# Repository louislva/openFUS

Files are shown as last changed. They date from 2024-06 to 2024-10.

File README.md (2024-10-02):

# openFUS: a cheap, open-source, easy to replicate FUS device for hackers & researchers

View [current design (subject to change)](/design/) 

### Background

Transcranial focused ultrasound (tFUS) is a non-invasive neuromodulation technique, which has millimeter precision and can reach any depth in the brain. It's safe, and has been used in humans to:

- [improve mood](https://www.frontiersin.org/articles/10.3389/fnhum.2020.00052)
- [reduce sensitivity to pain](https://www.jneurosci.org/content/44/8/e1011232023) (and [again](https://www.sciencedirect.com/science/article/pii/S1935861X20302746))
- [decrease amygdala activity (for treating anxiety)](<https://www.brainstimjrnl.com/article/S1935-861X(24)00040-8/fulltext>)

It's incredible that we have a **non-invasive** way to do the equivalent of putting a wire _anywhere_ in the brain and stimulating it. Why isn't this everywhere?

1. tFUS is relatively new & underdeveloped. It's quickly gaining steam (see [Prophetic](https://x.com/PropheticAI), etc.), but good human studies really only started coming out in the late 2010s!
2. It's still niche in academia, and the hardware is expensive. This means relatively few labs can do it.
3. No good treatment protocols, which makes effect sizes sub-therapeutic. We have the tool but we don't quite know how to use it (sonication parameters, environment, sequence / repetitions, etc.)

### How tFUS works

You wouldn't expect ultrasound could modulate the brain — electric currents or magnetic fields, sure, but acoustic waves? Apparently yes! The mechanisms are still unknown, but by changing the parameters of the ultrasound pulses, you can control whether you get a net excitatory or inhibitory effect.

Then, in order to get the ultrasound to the right part of the brain, you need to focus it. This can be done in many ways, but the easiest to illustrate, is if you have a bunch of weak ultrasound beams, which all converge at the same point:

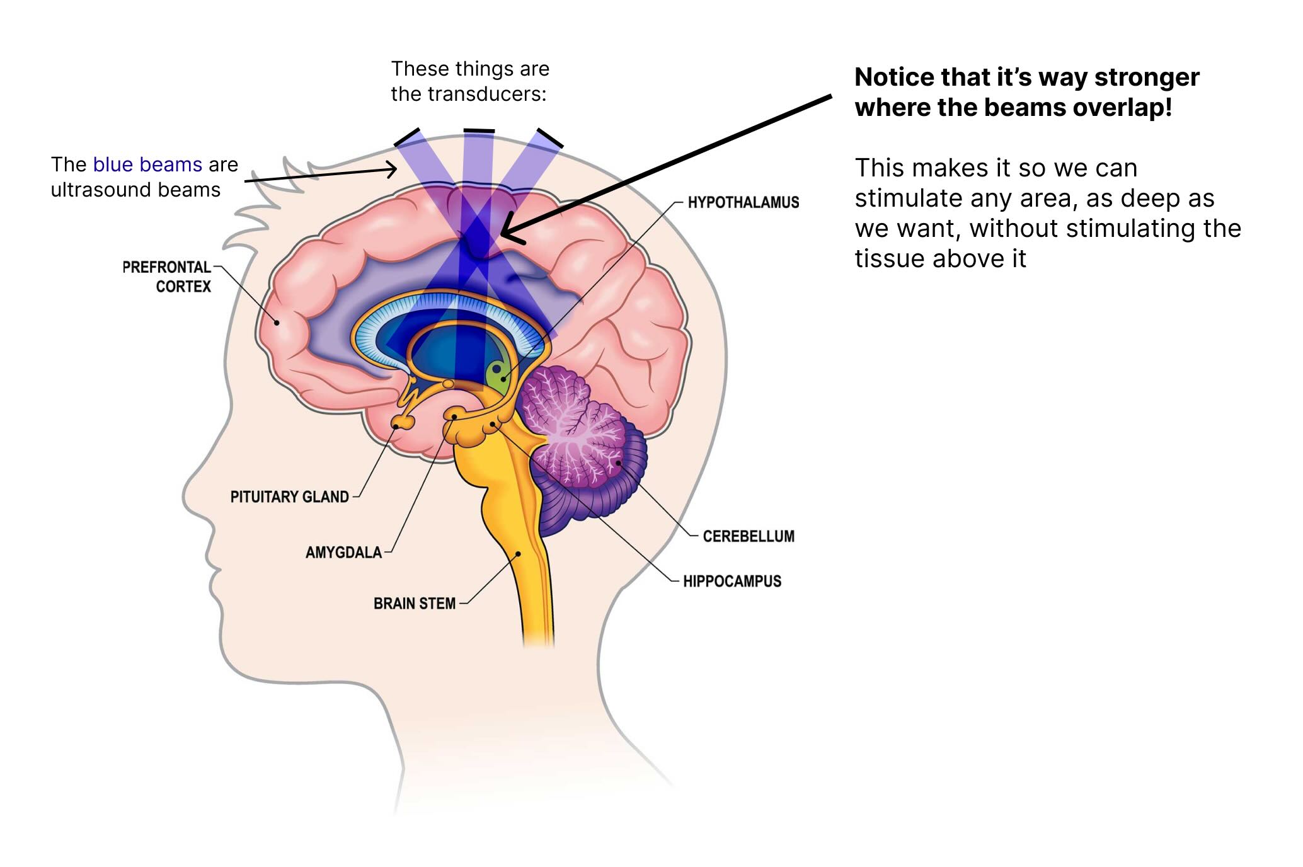
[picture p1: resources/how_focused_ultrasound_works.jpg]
how focused ultrasound works


The beam will be too weak to do anything at the surface, but at the focal point, it will be strong enough to affect neurons.

### Motivation for **openFUS**

Let's compare tFUS to EEG. Nowadays, every neuroscience _undergrad_ is working with EEG (because [OpenBCI](https://openbci.com/) sells $1000 EEGs). Even hackers and psychonauts can use it to make discoveries (for example, [Jhourney](https://x.com/stephen_zerfas/status/1755149844921057744) finding neural correlates of the 2nd jhana).

We've not reached this moment with tFUS yet, but when we do, it's gonna lead to [an explosion in neuroscience](https://sarahconstantin.substack.com/p/testing-human-augmentation) since we can easily and rapidly test hypotheses. Sonicate one area, give a subjective report, take an fMRI, repeat.

For this neuroscience renaissance to happen, **FUS needs to be more accessible**. We need an open-source starting point for engineers to build on top of, and independent researchers to buy and use.

**North star:** make a device theoretically capable of replicating ["Transcranial Focused Ultrasound to the Right Prefrontal Cortex Improves Mood and Alters Functional Connectivity in Humans"](https://www.frontiersin.org/articles/10.3389/fnhum.2020.00052), for less than $1k.

### Contributing

We need your help! Here are some things you can help out with:

- Great software (for neuronavigation, setting sonication params, self-blinding, peer-to-peer science, etc.)
- Great product design (for the handheld device itself)
- Driving electronics (e.g. amplify to generate LOTS of power as cheap as possible)
- Funding (we're not spending any time fundraising, but if you can wire cash with low overhead, it'd help a lot)

If you're interested in contributing, please reach out to Louis Arge [on Twitter](https://x.com/louisvarge), [by email](mailto:louis@muditalabs.ai), or if you have something very concrete: just open a PR.

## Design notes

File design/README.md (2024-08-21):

# openFUS design (subject to change)

This document serves as the reference for the current design of the openFUS device. It is not final, and subject to change as we iterate & learn.

## Stack

Here are the components, roughly listed from back to front:

- **"Driver" box**
    - **RF-proof case** (is this necessary?)
    - **Arduino** or Raspberry Pi
    - **[Driver electronics](/design/driving-and-wattage.md)**
        - AD9833
        - Coupling capacitor
        - Amplifier
- **"Pointer" handheld**
    - **Housing (water-proof)**
    - **Angled back panel**, to reflect any waves that end up making it through backing away orthogonally
    - **[Backing](/design/backing.md):** absorb waves that come out through the back, so they don't reflect and interfere in the forward direction
    - **Wires** that connect silver electrodes & the Driver
    - **[PZT-5H disc](/design/piezoelectric-element.md):** raw transducer element
    - **[Impedance matching (PZT to lens)](/design/impedance-matching.md):** Quarter-wave transformer
    - **[Lens](/design/lens.md):** concave lens, to focus the ultrasound waves
        - Material: Probably TPX/Polymethylpentene, which has almost same impedence as water/ultrasound gel/tissue
        - Shape: concave, since accoustic lenses are opposite of optical lenses (concave to focus, convex to diverge)
        - Exact shape: Use [`make_lens.py`](/make_lens.py) to design a lens - unsure this is actually right, let's see
        - Manufacturing: Probably buy a rod of TPX, slice it, and machine it
- **Ultrasound gel:** to fill the lens & make contact with skull or water tank, and couple the ultrasound waves to the skull
- Note: The electrodes to power the PZT-5H can be run through the impedance matching, if it's conductive (e.g. silver epoxy might be)

## Bill of materials (priced for 10 units)

- Arduino: $25
- AD9833: $12
- THS3091: $12
- Power Supply: $100
- RF box for housing Driver: ??
- 3d-printed housing for Pointer: ??
- Backing epoxy: ??
- Backing tungsten: ??
- PZT-5H: $25
- Lens: $25
- Silver epoxy: $20
- Ultrasound gel: $10
- PCB: ~$5
- Small electrical components (coupling capacitor, resistors, etc.): ~$10

Known costs: $245

Guess at the rest: $250

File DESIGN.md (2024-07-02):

# openFUS design (subject to change)

This document serves as the reference for the current design of the openFUS device. It is not final, and subject to change as we iterate & learn.

## Option A

Here are the components, roughly listed from back to front:

- [Off-the-shelf function generator](/design/driving-and-wattage.md)
    - Need sine waves, square waves are dangerous (because lots of overtones); this means we need a kind of expensive machine, probably.
    - Check how much reflection it can take (typically will say a %)
    - If needed, can use [Component I don't remember what's called (think, Isolator?) to redirect reflected waves]
    - How much power needed to replicate experiments?
- (RF-proof, water-proof) housing for transducer + electrodes on silver-epoxy
    - May be that RF-proofing matters somewhat less, bc we'll drive at somewhat higher power
    - Should have coaxial cables coming out of it
- Ultrasound transducer
    - **Angled back panel**, to reflect any waves that end up making it through backing, away orthogonally
    - **[Backing](/design/backing.md):** absorb waves that come out through the back, so they don't reflect and interfere in the forward direction
        - Casting epoxy + tungsten powder: Has low impedence (not quite water, but close), and tungsten powder will reflect waves around, so they can be attenuated for a longer time, on a longer path  
    - **[Impedance matching (backing):](/design/impedance-matching.md)** Quarter-wave transformer
        - Impedence needs to = sqrt(Z1 * Z2), where Z1 is the impedence of the backing, and Z2 is the impedence of the PZT-5H
        - Then you spread a quarter-wavelength of it, which will match the impedence between the two elements, theoretically bringing the reflection to 0
        - Manufacturing: ?? Ideally an epoxy, so it can be spread thin? Calculate how much weight needed for 1/4th wavelength for entire surface area, and put that amount on
    - **[PZT-5H disc](/design/piezoelectric-element.md):** raw transducer element
    - **[Impedance matching (lens):](/design/impedance-matching.md)** Quarter-wave transformer
        - Same trick, except now the impedence is between the PZT-5H and the lens
    - **[Lens:](/design/lens.md)** concave lens, to focus the ultrasound waves
        - Material: Probably TPX/Polymethylpentene, which has almost same impedence as water/ultrasound gel/tissue
        - Shape: concave, since accoustic lenses are opposite of optical lenses (concave to focus, convex to diverge)
        - Exact shape: Use [`make_lens.py`](/make_lens.py) to design a lens - unsure this is actually right, let's see
        - Manufacturing: Probably buy a rod of TPX, slice it, and machine it
- **Ultrasound gel:** to fill the lens & make contact with skull or water tank, and couple the ultrasound waves to the skull
- Note: The electrodes to power the PZT-5H can be run through the impedance matching, if it's conductive (e.g. silver epoxy might be)

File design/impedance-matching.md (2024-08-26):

# [Design](/design.md) → Impedance Matching: Lens & backing

We need to impedence match the [lens](/design/lens.md) (PP; 2.4 MRayl) and the piezoceramic (PZT-5H; 35 MRayl).

To do that, we can make a quarter-wave transformer layer, which needs to have an acoustic impedance of:

sqrt(2.4 * 35) = 9.17

We want this to be epoxy-based, since it'll be easy to customize, spread, and serve a dual purpose as an adhesive ("glue") for the lens. Ideally, we'd also want it to be conductive, so that it can used to power the piezoceramic. A good candidate is silver-epoxy, which is sometimes used as a matching layer.

### Applying it

Current idea:
1. Calculate speed-of-sound & then wavelength in the epoxy
2. Calculate epoxy volume: 30mm diameter * quater-wave thickness
3. Calculate epoxy weight: volume * density
4. Use a high-precision scale to place that amount of epoxy in the middle of the piezoceramic disc
5. Press the piezoceramic disc into the lens, spreading the epoxy evenly, and let it cure. (Probably inside of tube that prevents it from spilling out the sides)
6. Let it cure

### CircuitWorks CW2400 design

Estimated impedence (by density, new formula): 9.09 MRayls
Estimated speed of sound (by density, new formula): 2272 m/s
500khz wavelength: 4.54mm (2272 m/s / 500000 Hz)
500khz quater-wave: 1.14mm (4.54mm / 4)

So, how much weight of CW2400 do we need to get a 1.14mm thick layer?

Well, let's calculate the volume of the cylinder:

`V = π \* r^2 \* h`

r = 15mm
h = 1.14mm

V = 3.14 * 15mm^2 * 1.14mm = 805.82mm^3

And, the density of CW2400 is 4 g/cm^3, which is the same as 0.004 g/mm^3. So:

W = V * density = 805.82mm^3 * 0.004 g/mm^3 = 3.22g

Now it's 50/50 between Epoxy/Hardener, which means you should use 1.61g of Epoxy, and 1.61g of Hardener.

### Silver epoxy suppliers

Here are my <u>guesses</u> for the impedence of different pre-mixed silver-epoxies.

**EM-Tec AG29**

Estimated impedence (by reported mixture): 8.61 MRayls
Estimated impedence (by density): 8.20 MRayls

https://www.microtonano.com/EM-Tec-conductive-silver-filled-epoxy

**Em-Tec AG32**

Estimated impedence (by reported mixture): 6.25 MRayls

https://www.microtonano.com/EM-Tec-conductive-silver-filled-epoxy

**CircuitWorks CW2400**

Estimated impedence (by density): 10.5 MRayls
Estimated impedence (by mechanical properties, as analyzed by ChatGPT): 10 MRayls

https://eu.mouser.com/ProductDetail/Chemtronics/CW2400

**Bondline BONDLINE 2080**

Estimated impedence (by density): 10.18 MRayls

**MG 8330S**

Estimated impedence (by density): 7.73 MRayls

**MG 8330D**

Estimated impedence (by density): 8.20 MRayls

**MG 8331D**

Estimated impedence (by density): 5.78 MRayls
Study [claimed](https://www.sciencedirect.com/science/article/pii/S0041624X1100254X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) it was 2.6 MRayls. ???

**MG 8331S**

Estimated impedence (by density): 5.84 MRayls

### Non-silver epoxy matching layers

**AZ31B magnesium-alloy**

Reported impedence: 10.5 MRayls
https://www.sciencedirect.com/science/article/abs/pii/S0041624X22001500

**Parylene**

**Epo-Tek 301**

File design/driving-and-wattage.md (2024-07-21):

# [Design](/design.md) → Driving and Wattage

This is still very much in flux.

### Components

- Raspberry Pi or Arduino
- Breadboard
- Male and female jumper wires
- AD9833: Digital function generator (DIP variant)
- TODO: Power supply for AD9833 ??? (think Raspberry Pi can handle, actually)
- Coupling capacitor: Go from positive only AC signal, to positive and negative AC signal
- n * Op-amp circuit (in parallel)
    - THS3091: High-frequency op-amp
    - SOIC-8 Breakout Board
    - 49k ohm resistor in
    - 1k ohm resistor b
    - Power supply. Either [this](https://dk.rs-online.com/web/p/switch-mode-stromforsyninger-smps/0413655) or [this](https://dk.rs-online.com/web/p/switch-mode-stromforsyninger-smps/1368987); can use experimentation variable power supply for now
    - TODO: coupling capacitor on output
    - TODO: decoupling capacitor on power supply
- *Either: Send to PZT or have a 1.9 ohm resistor to mimic*
- *For prototyping: convert to cables for oscilloscope (this should be easy, since most oscilloscopes have those clamp-thingies you could just apply to male-ended jumper)*
- *Coaxial cable*
- *RF proof enclosure*

You can see a rough simulation in [driver-circuit.asc](/driver-circuit.asc) with LTSpice.

### Making it

You will need soldering equipment, particularly for soldering AD9833 and THS3091 onto their respective breakout boards.

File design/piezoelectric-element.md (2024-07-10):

# [Design](/design.md) → Piezoelectric Element

The piezoelectric element is the material that converts between electric and mechanical signals. There are lots of such materials. If you want high power for medical applications, you'll generally want PZT, specifically PZT-5H.

The wavelength is equal to double the thickness of the element.

So if you want a 500khz element:
- You can divide the speed of sound in PZT-5H (~4000m/s) to get the wavelength: 4000m/s / 500000khz = 8mm
- You can then divide by 2 to get the thickness (~4mm)

STEMINC is a reputable site, which sells PZT-5H discs (with no minimum order quantity): [30x4.2mm disc](https://www.steminc.com/PZT/en/pzt-ceramic-disc-30x42mm-s-500-khz)
- Their material is called SM411, but it's equivalent to PZT-5H.

### Why 500khz?

With tFUS, you get a tradeoff between resolution (higher frequency is better) and skull penetration (lower frequency is attenuated less, and can make it into the brain).

500khz is the sweetspot. In tissue, the speed of sound is approximately 1500m/s, meaning a 500khz wave is about 3mm. However, if you go much higher, you'll run into a lot of attenuation.

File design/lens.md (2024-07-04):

# [Design](/design.md) → Lens

**Material:** PP (Polypropylene)

**About PP:**

Density = 0.92 g/cm³
Speed of sound = 2470-2565 m/s

Acoustic impedance = 2.360 MRayl
Reflection with water = 5%

**Shape:** We can use the lens maker's formula to calculate the radius of curvature of the lens. We've created `make_lens.py` to help with this calculation, which exports the design to a `.obj` file.

**Validation:** TODO: Validate the lens in simulation using `k-wave` or `Field II`.

**Machining:** CNC machining is the best way. Working on converting `.obj` lenses to g-code paths.

Other options are:
- 3d printing: beware of small airgaps (since plastics may cool too quickly)
- Injection molding: no clue where to even start with this, feel free to submit a PR if you know how to do this

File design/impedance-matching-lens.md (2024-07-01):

# [Design](/design.md) → Impedance Matching Lens

We need to impedence match the [lens](/design/lens.md) (TPX; 1.66 MRayl) and the piezoceramic (PZT-5H; 34.2 MRayl).

To do that, we need a material with an acoustic impedance that is:

sqrt(1.66 * 34.2) = 7.53 MRayl

We want this to be epoxy-based, since it'll be easy to customize, spread, and serve a dual purpose as an adhesive ("glue") for the lens. Ideally, we'd also want it to be conductive, so that it can used to power the piezoceramic (with electrodes on the side, not in the way of the wave).

When mixing two materials (like epoxy and a filler), the formula for the acoustic impedance is:

\[ Z_{\text{mix}} = \sqrt{(Z_1 \cdot v_1 + Z_2 \cdot v_2)(v_1 + v_2)} \]

Here:
- \( Z_{\text{mix}} \) is the acoustic impedance of the mixture.
- \( Z_1 \) and \( Z_2 \) are the acoustic impedances of materials 1 and 2, respectively.
- \( v_1 \) and \( v_2 \) are the volume fractions of materials 1 and 2, respectively, where \( v_1 + v_2 = 1 \).

### Approach: Epoxy + Silver

[Per ChatGPT](#appendix-chatgpt-calculates-epoxy-silver-ratio), we can use a 7.5% mixture of epoxy and silver (by volume) to get an acoustic impedance of around 7.5 MRayls. The advantage of silver is that it's highly conductive, which is useful for powering the piezoceramic.

[Per ChatGPT](#apendix-chatgpt-calculates-epoxy-silver-speed-of-sound), the speed of sound in this mixture would be around 3951 m/s. TODO: calculate this by hand, seems fishy.

**How do we mix silver & epoxy?**

*Easy answer: Buy a premade silver-epoxy,** like [this one](https://www.mouser.com/ProductDetail/MG-Chemicals/8330S-21G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) (or for the [europoors](https://www.praud.pl/kleje_do_elektroniki/kleje_przewodzace_prad_elektryczny/dwuskladnikowe_kleje_epoksydowe/8331d_mg_chemicals))

Otherwise, my current understanding is: As long as the silver particles are small enough (like < 1/10th the wavelength, or something like that), evenly distributed, and similar sizes, they won't scatter or reflect the ultrasound.

For 500khz ultrasound, with a speed of sound of 3951 m/s, the wavelength is:

3951 m / 500000 = 0.007902 m = 7.902 mm

Which means the silver particles should be < 0.79 mm in size.

- Sigma Aldrich sells silver nanoparticles that are 8 μm (0.008 mm) in size. This is well under the 0.79 mm limit.

**How do we apply it precisely?**

From the wavelength we calculated, the **thickness of the layer** should be 7.902 / 4 = 1.975 mm, to act as a quarter-wave matching layer.

Current idea: Calcuate the weight of silver-epoxy needed for a 1.975 mm layer, on the area of the piezoceramic disc. Use a high-precision scale to measure the weight of the piezoceramic disc. Add silver-epoxy in the middle until the weight target is reached. Press the piezoceramic disc into the lens, spreading the silver epoxy evenly, and let it cure.

The lens should probably be wider than the piezoceramic disc, and have a machined inset in the bottom, to insert the piezoceramic disc into.

### Appendix: ChatGPT calculates epoxy-silver ratio

To find a mixture of epoxy and silver that gives an acoustic impedance around 7.5 MRayls, we use the weighted average formula for acoustic impedance:

\[ Z_{\text{mix}} = Z_1 \cdot v_1 + Z_2 \cdot v_2 \]

Here:
- \( Z_{\text{mix}} = 7.5 \times 10^6 \) Rayls
- \( Z_1 \) is the acoustic impedance of epoxy.
- \( Z_2 \) is the acoustic impedance of silver.
- \( v_1 \) and \( v_2 \) are the volume fractions of epoxy and silver, respectively, where \( v_1 + v_2 = 1 \).

Assuming:
- Acoustic impedance of epoxy (\( Z_{\text{epoxy}} \)): ~3 MRayls
- Acoustic impedance of silver (\( Z_{\text{silver}} \)): ~63 MRayls

Using these values:

\[ 7.5 \times 10^6 = (3 \times 10^6) \cdot v_1 + (63 \times 10^6) \cdot (1 - v_1) \]

Solving for \( v_1 \):

\[ 7.5 \times 10^6 = 3 \times 10^6 \cdot v_1 + 63 \times 10^6 \cdot (1 - v_1) \]
\[ 7.5 \times 10^6 = 3 \times 10^6 \cdot v_1 + 63 \times 10^6 - 63 \times 10^6 \cdot v_1 \]
\[ 7.5 \times 10^6 = 63 \times 10^6 - 60 \times 10^6 \cdot v_1 \]
\[ 7.5 \times 10^6 - 63 \times 10^6 = -60 \times 10^6 \cdot v_1 \]
\[ -55.5 \times 10^6 = -60 \times 10^6 \cdot v_1 \]
\[ v_1 = \frac{55.5 \times 10^6}{60 \times 10^6} \]
\[ v_1 = 0.925 \]

So, the volume fraction of epoxy (\( v_1 \)) is approximately 0.925 (or 92.5%), and the volume fraction of silver (\( v_2 \)) is approximately 0.075 (or 7.5%).

### Apendix: ChatGPT calculates epoxy-silver speed of sound

To find the speed of sound in a mixture of epoxy and silver with a given acoustic impedance, we use the relationship between acoustic impedance, density, and the speed of sound:

\[ Z = \rho \cdot c \]

where:
- \( \rho \) is the density of the mixture.
- \( c \) is the speed of sound in the mixture.

First, we estimate the density of the mixture. Assuming we know the densities of epoxy and silver:

- Density of epoxy (\( \rho_{\text{epoxy}} \)): ~1.2 g/cm³ (1200 kg/m³)
- Density of silver (\( \rho_{\text{silver}} \)): ~10.5 g/cm³ (10500 kg/m³)

Using the volume fractions \( v_1 \) and \( v_2 \) calculated previously:

\[ v_1 = 0.925 \]
\[ v_2 = 0.075 \]

The density of the mixture (\( \rho_{\text{mix}} \)) can be calculated as:

\[ \rho_{\text{mix}} = \rho_{\text{epoxy}} \cdot v_1 + \rho_{\text{silver}} \cdot v_2 \]

Plugging in the values:

\[ \rho_{\text{mix}} = (1200 \, \text{kg/m}^3) \cdot 0.925 + (10500 \, \text{kg/m}^3) \cdot 0.075 \]
\[ \rho_{\text{mix}} = 1110 \, \text{kg/m}^3 + 787.5 \, \text{kg/m}^3 \]
\[ \rho_{\text{mix}} = 1897.5 \, \text{kg/m}^3 \]

Now we use the acoustic impedance \( Z_{\text{mix}} = 7.5 \times 10^6 \) Rayls to find the speed of sound \( c_{\text{mix}} \):

\[ Z_{\text{mix}} = \rho_{\text{mix}} \cdot c_{\text{mix}} \]
\[ 7.5 \times 10^6 = 1897.5 \cdot c_{\text{mix}} \]
\[ c_{\text{mix}} = \frac{7.5 \times 10^6}{1897.5} \]
\[ c_{\text{mix}} \approx 3951 \, \text{m/s} \]

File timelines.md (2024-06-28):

**Lots of work (get started as early as possible):**
- [ ] Accoustic impedance matching layers
    - [ ] Get epoxy + filler (& make sure we know their correct speed of sound)
    - [ ] Learn how to mix solutions with correct impedance
    - [ ] Learn how to apply precisely
    - [ ] Learn how to cure
- [ ] Lens
    - [ ] Learn how to shape
    - [ ] Validate in simulation
    - [ ] Learn how to machine
    - [ ] Validate focus with hydrophone + water tank
        - [ ] Get access to hydrophone + water tank (do not wanna buy/make: very expensive, needs to be precise, calibrated, etc.)

**High lead time:**
- [ ] Acquire PZT-5H
    - [ ] Test how much wattage it can handle

**Other, relatively fast:**
- [ ] Get function generator
- [ ] Electronics to drive piezoceramic
- [ ] Housing (3D print or metal? May need EM shielding + waterproofing near front)

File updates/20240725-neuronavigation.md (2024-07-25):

# Neuronavigation

### Our approach: ArUco markers + Invesalius

We're going to use [Invesalius](https://github.com/invesalius/invesalius3) neuronavigation software, and make an [ArUco](https://docs.opencv.org/4.x/d5/dae/tutorial_aruco_detection.html) integration to track it with a single webcam. Cheap, accurate, and easy to use.

We need to make hardware which has the ArUco markers on it. The points we need to track are: the ears + the device itself. With the ears especially, it's important that the ArUco markers are not occluded by slight turns of the head. Current ideas:

- Ear markers (Idea #1): ear plug + tooth pick + ArUco sign sticking out
- Ear markers (Idea #2): clamp on ear + ArUco sign attached to it
- Ear markers (Idea #3): glue a thin plastic sign-post to [a JLab sports ear bud](https://www.amazon.com/JLab-Air-Sport-Featuring-Bluetooth/dp/B09RGB47FJ?th=1)
- Device markers: 3d print a flat surface in shell + a stencil + spray paint an ArUco marker

### Other approaches you could do

- [End-to-end head 6D pose tracking](https://arxiv.org/pdf/2309.07654v1)
- Track ear keypoints from 2 views & estimate their 3d positions
    - [ViTPose](https://github.com/vitae-transformer/vitpose)
    - [X-Pose: track any keypoints](https://github.com/IDEA-Research/X-Pose)
- [End-to-end multiview pose tracking](https://www.youtube.com/watch?v=GAqhmUIr2E8)
- [Track ArUco markers placed on ears from 2 views & estimate their 3d positions with classic computer vision](https://docs.opencv.org/4.x/d5/dae/tutorial_aruco_detection.html)
- [Use Cotracker to just place tracks on ears initially and then HOLD STILL](https://co-tracker.github.io/)

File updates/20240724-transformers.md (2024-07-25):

# Transformers (WIP)

Okay, so: it's pretty easy to get [an RF transformer](https://eu.mouser.com/ProductDetail/994-SWB1040-PCL), but they're typically only rated for 0.25W.

However, even though our pulse power is 4.5W, our duty cycle may only be something like 5%, putting our average power at 0.225W (which is below the 0.25W rating).

We need to **stress test in real-life**, but the theoretical constraints are:

- Overheating: should be fine, since that depends more on average power than peak power
- Core saturation: ferrite should be able to go kinda high, so should be fine, but let's test it

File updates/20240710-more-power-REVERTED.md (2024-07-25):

# ~~Get more power + void the transformer problem~~ (REVERTED, because stupid idea)

Current problems:
- Even if no transformer problems, our op-amp only gives about 2.32W. This may not be enough power, depending on physics of PZT, lens, etc.
- Regardless, transformers suck ass & make the circuit more complicated. To limit to 300mA, we need to add resistance, which I think gives impedence mismatch problems.

Big solution: Put n op-amps in parallel, giving us n * 300mA of max current.

## How big n?

Ideally, we add no resistance, and only lower the voltage, such that the PZT (at 1.9 ohms), draws the power it needs. Let's assume we want to bring at max 5W to the PZT:

Given 5W, and 1.9ohms, we can calulate the voltage should be:

P = V^2 / R
V = sqrt(P * R)
V = sqrt(5W * 1.9ohms)
V = 3.08V

With 3.08V, the current draw will be:

I = V / R
I = 3.08V / 1.9ohms
I = 1.62A

Which means:

n = ceil(1.62A / 300mA) 
n = 6

So we need 6 op-amps in parallel to get 5W with no transformers or added impedence. We should, in this scenario also make the gain lower, since we don't need or want 15V.

## A more general python script to calculate:

```python
import math

def peak_to_rms(peak: float):
    return peak / math.sqrt(2)

MAX_CURRENT = peak_to_rms(0.31)

def wattage_to_op_amps(W: float, load_R: float = 1.9):
    # P = V^2 / R
    # V = sqrt(P * R)
    V = math.sqrt(W * load_R)
    I = V / load_R

    n_opamps = math.ceil(I / MAX_CURRENT)
    return n_opamps, V

print(wattage_to_op_amps(5))
```

The cost for, let's say 8 opamps is $12 * 8 = $96. This is more expensive than transformers (by a lot), but simpler.

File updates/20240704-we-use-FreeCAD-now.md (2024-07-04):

# Switch from bespoke Python script (`make_lens.py`) to FreeCAD

Lmao. Insanely rookie mistake. I was like, huh, I need to parametrically generate a lens model. Surely a Python script that manually writes an `.obj` is the best way to do that?

NO! This is what CAD software is for. It's literally programmatic by default. Have made [`lens.FCStd`](/lens.FCStd) which replaces [`make_lens.py`](/make_lens.py).

Just click `VariableHolder_EDIT_ME`, and go to properties -> Lens, and you can change the variables.

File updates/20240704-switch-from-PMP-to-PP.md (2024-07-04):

# Switch from PMP (polymethylpentene, aka TPX) to PP (polypropylene) for the accoustic lens

The constraints on the lens is:
- **Impedence match next layer** (ultrasound gel) best possible, to minimize interface reflections
- **Large IOR** (the number that determines it's lensing-power; derived from ratio of speed of sound in lens vs next layer)
- **Low cost**

Originally we were planning to use PMP, since it impedence matches water/gel/tissue very well & is common in sonography for this reason.

However, I've decided we will switch to PP, since:
- We don't care as much about impedence matching in focused ultrasound as in imaging (since there is no image which reflections will distort). See [below]() for the difference in reflection %
- Much higher IOR, meaning lens can be **47% thinner**, which will make it easier to fill up with ultrasound gel
- **82% cheaper** + we need **34% less volume** for same lensing, making it a total of **89% reduction in cost**
- Easier to source and machine, since PP is much more common

### Spec differences

| Property | PMP (Polymethylpentene) | PP (Polypropylene) |
|---|---|---|
| Price (goodfellow) | [€2,781](https://www.goodfellow.com/eu/tpx-mx004-pmp-rod-1000003171) | [€482 (€241 * 2)](https://www.goodfellow.com/eu/pp-rod-1000170613) |
| Speed of sound | [2095 m/s](https://www.sciencedirect.com/science/article/abs/pii/S0301562911002857), [2097 m/s](https://www.osti.gov/servlets/purl/1574369) | [2565 m/s](https://www.ndt.net/links/proper.htm), [2470 m/s](https://www.signal-processing.com/table.php) |
| Density | [0.83 g/cm³](https://en.wikipedia.org/wiki/Polymethylpentene) | [between 0.895 and 0.92 g/cm³](https://plasticseurope.org/plastics-explained/a-large-family/polyolefins/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,plastic%20with%20the%20lowest%20density.) |
| Acoustic impedance | 0.83 g/cm³ * 2095 m/s = 1.7385 MRayl | 0.92 g/cm³ * 2565 m/s = 2.360 MRayl |
| Reflection with water | ((1.7385 - 1.48) / (1.7385 + 1.48))^2 = 0.006 (0.6%) | ((2.328 - 1.48) / (2.328 + 1.48))^2 = 0.050 (5.0%) |

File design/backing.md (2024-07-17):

# [Design](/design.md) → Backing

The purpose of the backing, is to absorb waves that come out of the other end (since the PZT will make a symmetrical wave, and we only want the forward wave).

This may not be super important, since we're not doing imaging; but getting a lot of reflections still gives me the heebie-jeebies.

It needs to do this with minimal reflection, meaning you want a material with:
- Same impedence as the PZT-5H (around 32 MRays)
- High attenuation (so it actually absorbs the wave)

A very typical way to do this, is to make tungsten epoxy. Tungsten has a high density, which means it has a high impedence. The more you put in, the higher the impedence.

You can make this yourself, with fine tungsten powder, and low-viscosity epoxy resin. You may also need to rotate it while it cures, since tungsten is heavy and will fall to the bottom.

### Materials

- [Tungsten powder (smaller than 1/16th wavelength)]()

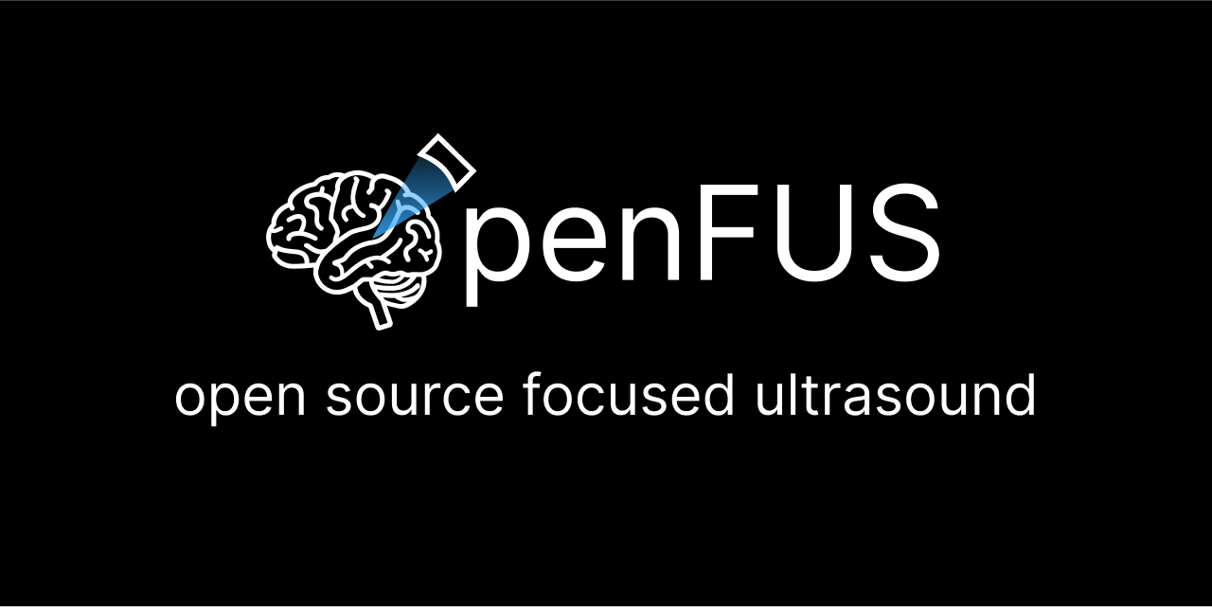
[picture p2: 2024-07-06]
github-social-preview.png

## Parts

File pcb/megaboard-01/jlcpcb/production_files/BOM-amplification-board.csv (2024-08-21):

Comment | Designator | Footprint | LCSC
CC0603KRX7R9BB104 | C1 | C_0603_1608Metric | C14663
RTT025002FTH | R3 | R_0402_1005Metric | C166559
THS3091DDAR | U1 | TI_SO-PowerPAD-8_ThermalVias | C181226
0603WAF1001T5E | R2 | R_0603_1608Metric | C21190
Conn_01x01_Pin | J1,J2,J4,J5 | PinHeader_1x01_P2.54mm_Vertical | C213184
Conn_01x03_Pin | J3 | PinHeader_1x03_P2.54mm_Vertical | C49257
RT0603BRE0750RL | R1 | R_0603_1608Metric | C849792

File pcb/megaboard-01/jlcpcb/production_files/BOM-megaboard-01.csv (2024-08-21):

Comment | Designator | Footprint | LCSC
C116241 | C7,C8 | CP_Elec_8x10 | C116241
C14663 | C1,C2,C4,C6 | C_0603_1608Metric | C14663
AD9833xRM | U2 | MSOP-10_3x3mm_P0.5mm | C1519069
RTT025002FTH | R3 | R_0402_1005Metric | C166559
C1779 | C3 | C_0805_2012Metric | C1779
C17901 | R10,R11,R12,R13,R4,R5,R6,R7,R8,R9 | R_1206_3216Metric | C17901
THS3091DDAR | U1 | TI_SO-PowerPAD-8_ThermalVias | C181226
0603WAF1001T5E | R2 | R_0603_1608Metric | C21190
Conn_01x01_Pin | J1,J2,J4,J5 | PinHeader_1x01_P2.54mm_Vertical | C213184
C37208 | J6 | PinHeader_1x06_P2.54mm_Vertical | C37208
C492401 | J7,J8 | PinHeader_1x02_P2.54mm_Vertical | C492401
Conn_01x03_Pin | J3 | PinHeader_1x03_P2.54mm_Vertical | C49257
C558756 | X1 | Crystal_SMD_7050-4Pin_7.0x5.0mm | C558756
C57112 | C5 | C_0603_1608Metric | C57112
RT0603BRE0750RL | R1 | R_0603_1608Metric | C849792
SWB1040-PCL | T1 | SWB1040PCL

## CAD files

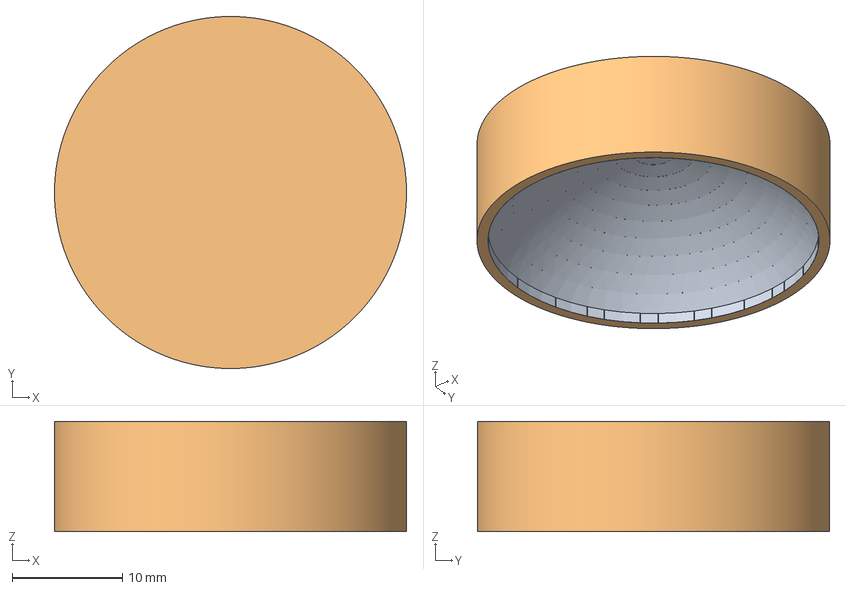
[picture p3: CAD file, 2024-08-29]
cad/lens-convex-silicone.FCStd
32.0 x 32.0 x 10.0 mm
Cast
Cast (Meshed)

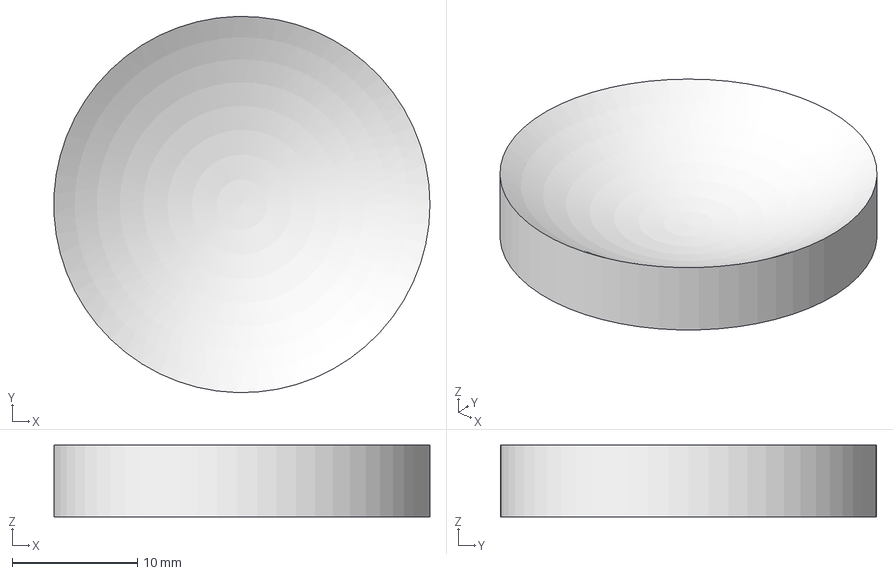
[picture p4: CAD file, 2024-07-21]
cad/outputs/lens-60mm-WAS-MACHINED-IN-PP-BY-XOMETRY.step
30.0 x 30.0 x 5.73 mm

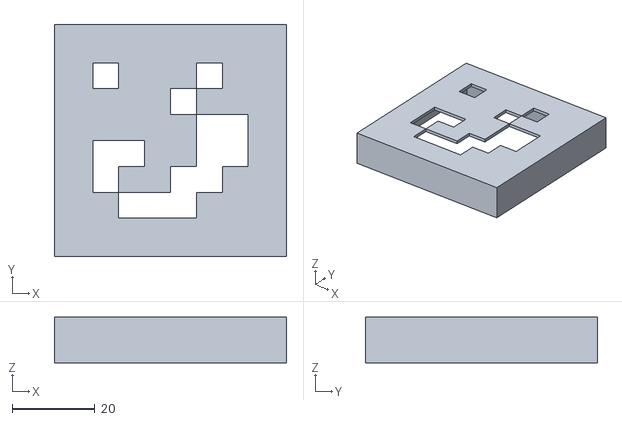
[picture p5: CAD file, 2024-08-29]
render/qr-21.stl
56.0 x 56.0 x 11.0

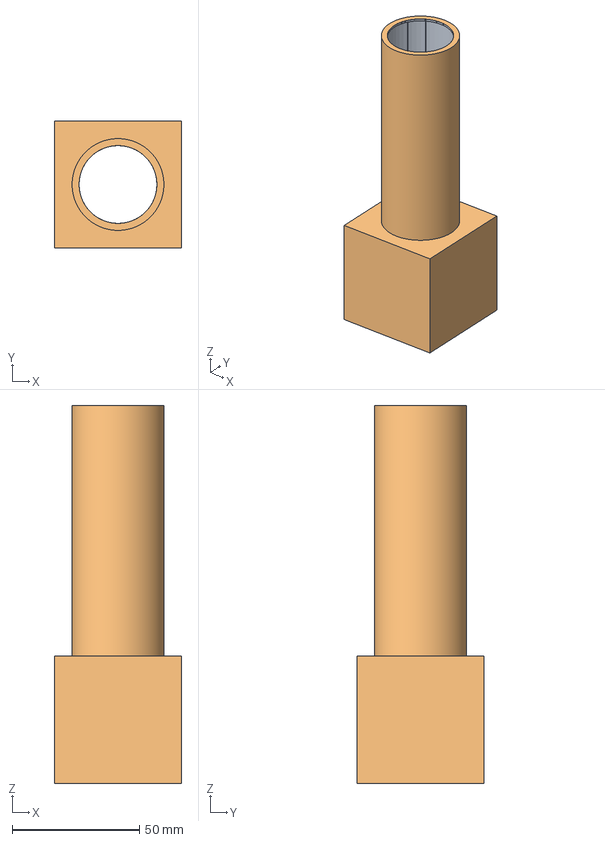
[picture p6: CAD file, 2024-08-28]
cad/case.FCStd
50.0 x 50.0 x 148.3 mm
Case
Case (Meshed)

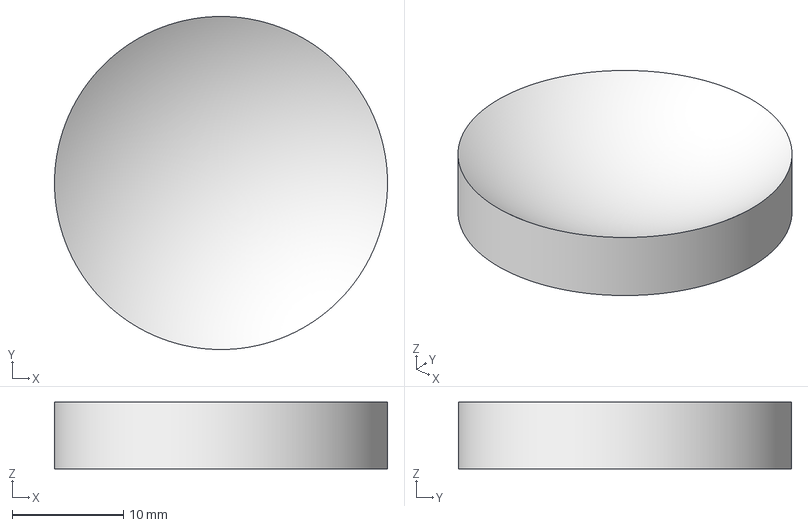
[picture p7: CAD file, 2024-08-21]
cad/lens-concave-PP.FCStd
30.0 x 30.0 x 6.02 mm

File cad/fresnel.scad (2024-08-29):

/*
    This module is the for generating fresnel lens models and molds
*/
$fs = 0.01;

SPHERE_FACETS = 320;
CYLINDER_FACETS = 96;

LENS_R  = 18; // 35mm focal length, offset by fresnel being roughly 5cm tall
LENS_D  = 30;
LENS_T  = 2;
BASE_T  = 2;
N_SECTIONS = 7;



module fresnel_lens( lens_radius    = LENS_R,
                     lens_thickness = LENS_T,
                     num_sections   = N_SECTIONS
                   )
{
  for (n = [1:num_sections])
  {
    t_n  = n*lens_thickness;
    a_n  = sqrt((LENS_D - t_n)*t_n);
    
    t_nm1 = (n-1)*lens_thickness;
    a_nm1 = sqrt((LENS_D - t_nm1)*t_nm1);
 
    intersection()
    {
      translate([0,0,-(lens_radius - t_n - BASE_T)])
      sphere(r=lens_radius, $fn=SPHERE_FACETS);
      difference(){
        cylinder(h=lens_radius, r=a_n,   $fn=CYLINDER_FACETS);
        cylinder(h=lens_radius, r=a_nm1, $fn=CYLINDER_FACETS);
      }
    }
  }
}

MOLD_THICKNESS = 10;

module fresnel_lens_mold( lens_radius    = LENS_R,
                          lens_thickness = LENS_T,
                          num_sections   = N_SECTIONS,
                          mold_thickness = MOLD_THICKNESS
                         )
{
  t_N  = num_sections*lens_thickness;
  a_N  = sqrt((LENS_D - t_N)*t_N);
  
  translate([0,0,mold_thickness])
  rotate(a=180, v=[1,0,0])
  difference(){
    translate([0,0,mold_thickness/2])
    cube([2.2*a_N,2.2*a_N, mold_thickness], center=true);
    translate([0,0,-lens_thickness/2])
    #fresnel_lens(lens_radius = lens_radius,
                 lens_thickness = lens_thickness,
                 num_sections = num_sections
                 );
  }
}
/******************************************************************************/
//rendering of part

// fresnel_lens();
fresnel_lens_mold();

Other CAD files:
render/device.blend
render/just-focus.blend
render/qr.blend
render/transducer-stack.blend

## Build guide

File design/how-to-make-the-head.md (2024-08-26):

# The Transducer Head

Ingredients:
- 3d-printed **Holder** from `case.FCStd`
- **Lens** - either Silicone Convex made from pouring silicone in 3d printed mold (`lens-convex-silicone.FCStd`), or a PP Concave lens, made by CNC-milling polypropylene into `lens-concave-PP.FCStd` shape.
- **CW2400** silver epoxy tubes
- **Piezo** disc (30x4.2mm from STEMINC)
- **Red wire**
- **Black wire**

Tools:
- A mg scale
- A toxic oven
- (Wire-stripper, if you're not handy)
- Soldering iron + solder
- Latex protective gloves + ventilated, isolated box for working with epoxy (VERY TOXIC)

Instructions:

0. Put on two layers of latex gloves, have prepare kitchen towels nearby, have toxic trash bag nearby.
1. Heat up oven to 60C (highest possible temperature for PLA Holder, lowest possible for CW2400).
2. Strip 1cm of insulation from both ends of the **Red wire** & **Black wire**.
3. Place the **Piezo** disc inside the **Holder**, on top of a **Milligram scale**.
4. Very slowly and carefully pour 1.61g of **CW2400** epoxy and 1.61g of **CW2400** hardener onto the middle of the **Piezo** disc. It's hard to stop at 1.61g, so you often accidentally go a little over - try to correct for this by stopping early!
5. Stir it thoroughly for 2 minutes.
6. Stick the stripped **Red wire** into the hole on the side of the **Holder**.
7. Place the **Lens** on top of the **CW2400**, and press down until the layer is flattened - do not press too hard or long, as this can push it into the creaks between the **Holder** and the **Piezo**/**Lens**.
8. Put it in the oven for 10 minutes.
9. Remove from oven, and let it cool down. Let it harden overnight.
10. Turn it around (with the lens downwards)
11. Add solder to the **Black wire**
12. Place the **Black wire** onto the bottom of the **Piezo** disc, thorugh the hole in the **Holder**, and apply soldering iron to the **Black wire** for a few seconds so it's well attached to the **Piezo** disc. Add a little more solder, if needed.
13. You're done!

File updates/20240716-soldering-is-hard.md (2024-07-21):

# Woops: Soldering is hard

So, turns out AD9833 is *tiny*, which means it's complicated to solder. Didn't realize this.

The [AD9833](https://eu.mouser.com/ProductDetail/Analog-Devices/AD9833BRMZ-REEL7?qs=BpaRKvA4VqGlyZCX2gCZvQ%3D%3D) uses **MSOP-10** which is the very small 10-pin SMD (surface-mount) interface. The [THS3091](https://eu.mouser.com/ProductDetail/Texas-Instruments/THS3091D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) uses **SOIC-8**.

For the two types of SMD, we can use **breakout boards** that convert from **[the SMD] to DIP**. You can directly attach jumper wires to DIP.
- ~~[MSOP-10 Breakout Board](https://dk.farnell.com/aries/lcqt-msop10/ic-adaptor-10msop-to-dip-2-54mm/dp/2476034)~~
    - Just get a pre-broken-out [AD9833](https://www.amazon.de/-/da/gp/product/B0C6R1RZP4)
- [SOIC-8 Breakout Board](https://dk.farnell.com/aries/lcqt-soic8-8/ic-adaptor-8-soic-to-dip-2-54mm/dp/2476033)

### How to solder (ChatGPT cheatsheet)

Sure, let's get you started with soldering! Here's a beginner's guide to help you solder an MSOP-10 onto an adapter.

### **Concepts**

1. **Soldering**: The process of joining two or more electronic components together by melting solder around the connection. The solder cools and forms a permanent bond.

2. **Solder**: A metal alloy used to create a conductive joint between metal surfaces. Typically, it's a mixture of tin and lead, but lead-free solders are also common.

3. **Flux**: A chemical cleaning agent used to remove oxidation from the metal surfaces to be soldered, allowing the solder to flow and bond more effectively.

### **Ingredients and Tools**

1. **Soldering Iron**: A tool with a heated tip to melt the solder. For your task, a fine tip is recommended.
   - Temperature: Adjustable (350-400°C or 662-752°F).

2. **Solder**: Thin wire solder, preferably 60/40 tin-lead or a lead-free alternative.

3. **Flux Pen or Paste**: Helps the solder flow better and prevents oxidation.

4. **Soldering Iron Stand**: To safely hold the hot soldering iron when not in use.

5. **Sponge or Brass Wire Cleaner**: For cleaning the soldering iron tip.

6. **Tweezers**: To hold small components in place.

7. **Magnifying Glass or Microscope**: To see small components clearly.

8. **Desoldering Braid or Pump**: To remove excess solder if needed.

9. **MSOP-10 Adapter**: The adapter you will solder the MSOP-10 onto.

10. **ESD Mat and Wrist Strap**: To prevent electrostatic discharge from damaging sensitive components.

### **Steps**

1. **Preparation**:
   - Clean the workspace.
   - Secure the MSOP-10 adapter on a non-slip mat or a PCB holder.
   - Put on the ESD wrist strap and ensure it’s grounded.

2. **Tin the Soldering Iron Tip**:
   - Heat the soldering iron.
   - Apply a small amount of solder to the tip once it’s hot.
   - Wipe the tip on the sponge or brass wire cleaner to remove excess solder.

3. **Apply Flux**:
   - Use a flux pen or paste to apply a small amount of flux to the pads of the MSOP-10 adapter.

4. **Position the MSOP-10**:
   - Use tweezers to carefully place the MSOP-10 chip on the adapter, aligning the pins with the pads.

5. **Tack Solder One Pin**:
   - Heat the pad and pin with the soldering iron, then apply a small amount of solder. This will hold the chip in place.

6. **Solder the Remaining Pins**:
   - Apply a small amount of solder to the tip.
   - Touch the soldering iron to each pin and pad briefly, allowing the solder to flow and form a joint.
   - Repeat for all pins, ensuring no solder bridges form between pins.

7. **Inspect the Joints**:
   - Use a magnifying glass or microscope to inspect each solder joint.
   - If there are solder bridges, use the desoldering braid or pump to remove excess solder.

8. **Clean the Board**:
   - Remove any residual flux with a suitable cleaner if necessary.

### **Tips**

- **Patience**: Take your time, especially with small components.
- **Practice**: Practice on some scrap components or old PCBs if possible.
- **Safety**: Work in a well-ventilated area and be cautious with the hot soldering iron.

### **Troubleshooting**

- **Cold Joints**: If the solder joint looks dull or grainy, it’s a cold joint. Reheat the joint and apply a bit more solder.
- **Bridges**: If solder bridges between pins, use desoldering braid or a solder sucker to remove excess solder and retry.

That's the basic rundown! Soldering can be tricky at first, especially with small components, but with practice, you'll get the hang of it. Good luck!

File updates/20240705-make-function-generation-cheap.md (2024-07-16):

# Make function generation cheap

Previously was thinking something like use \~whatever function generator\~ you have. However, this was stupid, for a few reasons:
- Function generators cost $400
- They don't actually give a lot of wattage: so you'd still need amplification

If you already need amplification, there's no reason to use a function generator, instead of a cheap Signal Generator like the AD9833, paired with an amplifier + a microcontroller (for pulsing, safety limits, etc.)

### AD9833

This generates positive-only sine waves, from a Raspberry Pi or Arduino.

- Clock rate: 25 MHz 
    - This means that at 500khz, we get 50 steps per wave.
    - Per my calculations, this results in 0.8% THD (total harmonic distortion), which is negligible.
- Voltage: it goes 0.038V to 0.65V

### AC coupling: Capacitor

So, AD9833 generates positive-only "unipolar" sine waves.

Let's imagine it's just from 0V to 1V, for simplicity. The way you should think about it is that the output is *really* a combination of:
- An AC signal, from -0.5V to 0.5V
- A constant DC signal, at 0.5V

That means the peak becomes: 0.5V + 0.5V = 1V

And the trough becomes: -0.5V + 0.5V = 0V

Now, we want to convert this into a proper, bipolar signal. What we can do is use a **coupling capacitor** to "strip" the DC signal away, leaving us only with the -0.5V to 0.5V AC signal, centered around 0V.

The value of the capacitor should be *at least* 1 µF, in order to support the coupling of a 500khz signal. This we can calculate with the cutoff frequency formula:

fc = 1 / (2 * π * R * C)

Where:
- fc is the cutoff frequency (which should be 1/10th of the desired signal frequency, 500khz, to not cutoff the actual signal)
- R is the load impedance,
- C is the capacitance.

Which we can solve for C:

C = 1 / (2 * π * R * fc)

If **R = 50 (standard impedence)**, then:

C = 1 / (2 * π * 50Ω * 50khz)

C = 6.36619772e-8

C = 64 nF

<u>So we need a 64 nF capacitor.</u>

However, if **R = 0.7 MΩ** (as is the case in THS3091 amp), it becomes:

C = 1 / (2 * π * 0.7MΩ * 50khz)

C = 4.5472841e-12 F

C = 4.5 pF

<u>So a 4.5 pF capacitor would be more appropriate.</u>

Increasing the capacitor *decreases* the minimum cutoff frequency, so I think most small-ish capacitors are "small enough" to block DC, actually.

Here's a [link to browse 0.056uF-0.068uF](https://eu.mouser.com/c/rf-wireless/rf-capacitors/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)

### Op-amp circuit

May be a cheaper alternative to the amplifier below.

Need an op-amp capable of handling 500khz (meaning high slew rate), needs high voltage (around 30V will give 5W, current permitting), and needs high current (at least 166mA, to do 5W at 30V).

I quite like: [THS3091](https://www.ti.com/product/THS3091)

I think we can expect the gain to be 610 V/V, because the GBWP (gain bandwidth product) is 305 MHz, and we're at 500khz:

305 MHz / 500 kHz = 610

Let's assume we'll get about -15 V to +15 V output, since power supply is 32 V.

If we max out the AD9833, we'll get about -300mV to 300mV (post coupling capacitor). If we put it to it's minimum, I believe we'll get about 5% of that, meaning -15mV to 15mV (5%, because we need ~50 power levels out of the 2^10 possible ones, since we have 50 samples. Will probably need more in practice, bc sine waves aren't linear, but around there should be okay).

Let's choose the -300mV to 300mV configuration. This means we need 50 V/V to get to +15V. This means we need the following resistors in a non-inverting configuration:

1. **Feedback Resistor (Rf):** This resistor will be placed between the output of the op-amp and the inverting input.
2. **Input Resistor (Rin):** This resistor will be placed between the inverting input and the ground.

Because:

gain = 1 + Rf/Rin

For a gain of 50 V/V:

50 = 1 + Rf/Rin

Rf/Rin = 49

Rf = 49 * Rin

So, if you choose Rin = 1kΩ

Rf = 49 * 1kΩ = 49kΩ

Therefore, you can use a 1 kΩ resistor for Rin and a 49 kΩ resistor for Rf to achieve the desired gain of 50 V/V.

This configuration should provide the required amplification to achieve a peak output of ±15V from the input signal of ±300mV, enabling the generation of a higher voltage sine wave signal suitable for your application.

We might wanna get a 40kΩ resistor for Rin, to get a bit less gain, in case 50 results in clipping.

###### Impedence matching

Before the op-amp, I do not believe impedence matching is necessary, because the op-amp has such high input impedance that no current will flow.

After the op-amp, you have the following:
- [Op-amp output impedance](https://www.ti.com/lit/ds/symlink/ths3091.pdf): 0.06 Ω
- PZT-5H disc: 1.9 Ω

ChatGPT seems to be very confident that this won't be a problem, because:
- Low impedences overall, and the source is lower than the load (good).
- It's a small circuit, and a 500khz signal is a 600 meter wavelength, won't have reflections.

However, at 1.9 Ω, the PZT will draw > 5A, which is way to high. The op-amp is rated for 310mA.

###### Transformation

**Source (THS3091, op-amp):**

Voltage (peak): 15V
Voltage (rms): V_peak / sqrt(2) = 10.6V
Max current: 310mA
Max current (rms): I_peak / sqrt(2) = 219mA
Max power: 10.6V * 219mA = 2.32W

**Load (PZT-5H disc):**

Impedence: 1.9Ω

This means, to get it to draw 2.32W, the voltage must be:

V = sqrt(P * R)
V = sqrt(2.32W * 1.9Ω)
V = 2.09V

We can double check:

I = 2.09V / 1.9 = 1.1A
W = 1.1A * 2.09V = 2.299W

**Transformer:**

Since the load needs 2.09V, and the source gives 15V, we need a step-down ratio of:

15V / 2.09V = 7.35

Which is <u>7.35 : 1</u> or <u>1 : 0.14</u> depending on how you look.

Sourcing a transformer seems hard, but this website has some interesting search tools: https://www.coilcraft.com/en-us/products/transformers/

(Note to self: I can't for the life of me find a good tranformer, but I can find 0.25W transformers, so could probably just put in parallel)

### (Maybe: Isolator)

It might be a problem for the Amp & AD9833 that waves come back from reflections. Let's just test this emperically, these components are cheap. If it's a problem, we need an isolator.

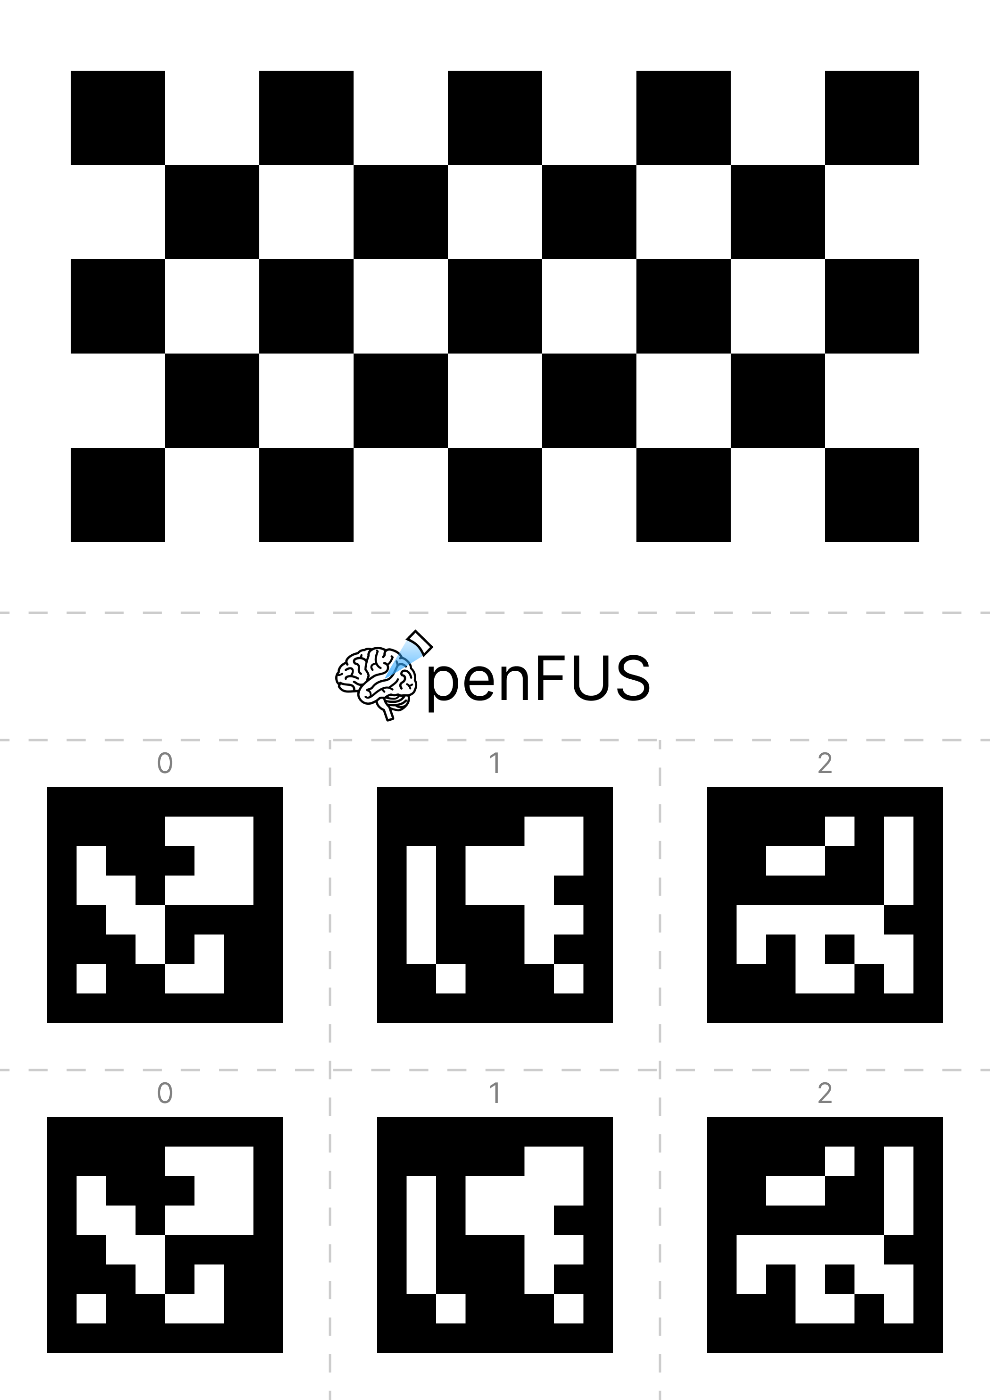
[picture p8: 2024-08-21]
neuronavigation/print/page-1.png

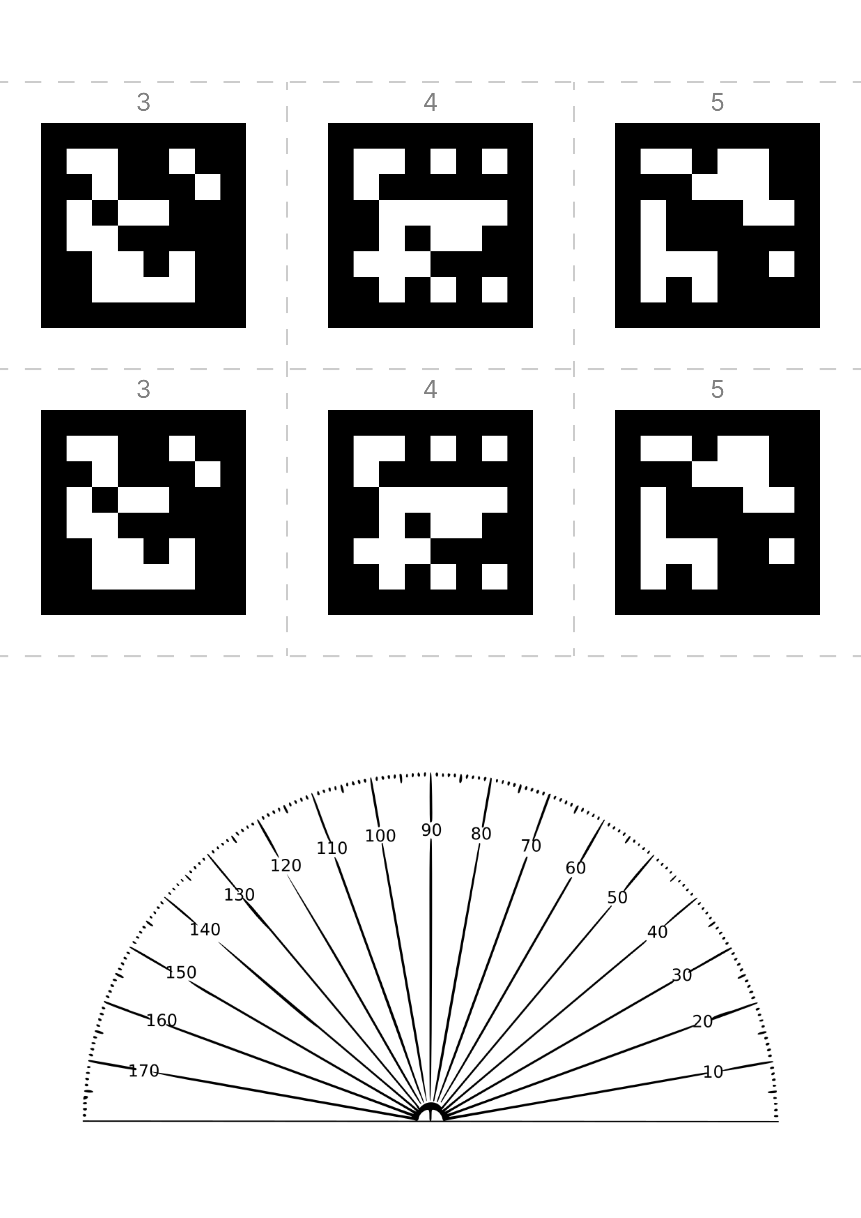
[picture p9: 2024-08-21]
neuronavigation/print/page-2.png

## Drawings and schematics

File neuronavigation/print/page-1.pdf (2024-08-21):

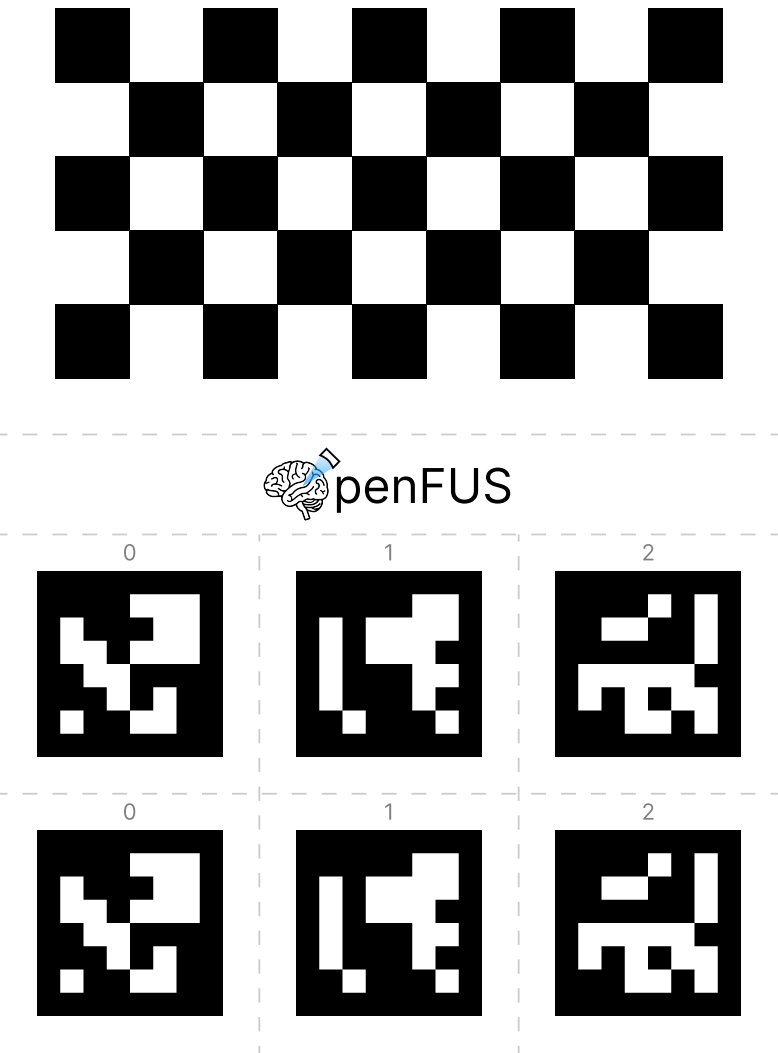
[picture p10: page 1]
penFUS

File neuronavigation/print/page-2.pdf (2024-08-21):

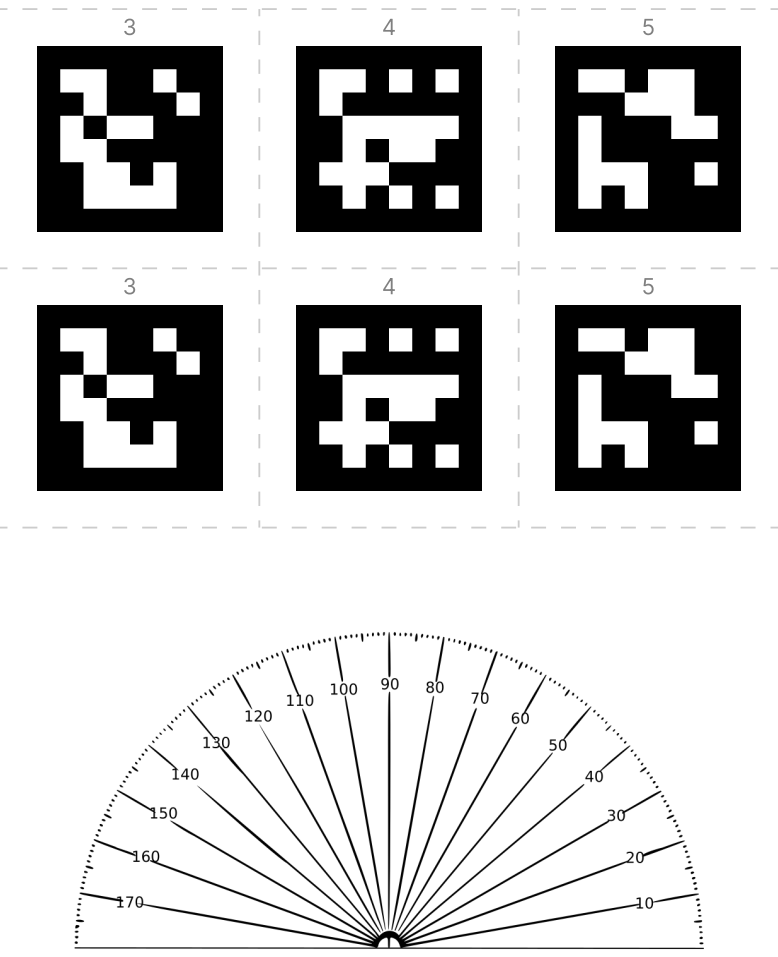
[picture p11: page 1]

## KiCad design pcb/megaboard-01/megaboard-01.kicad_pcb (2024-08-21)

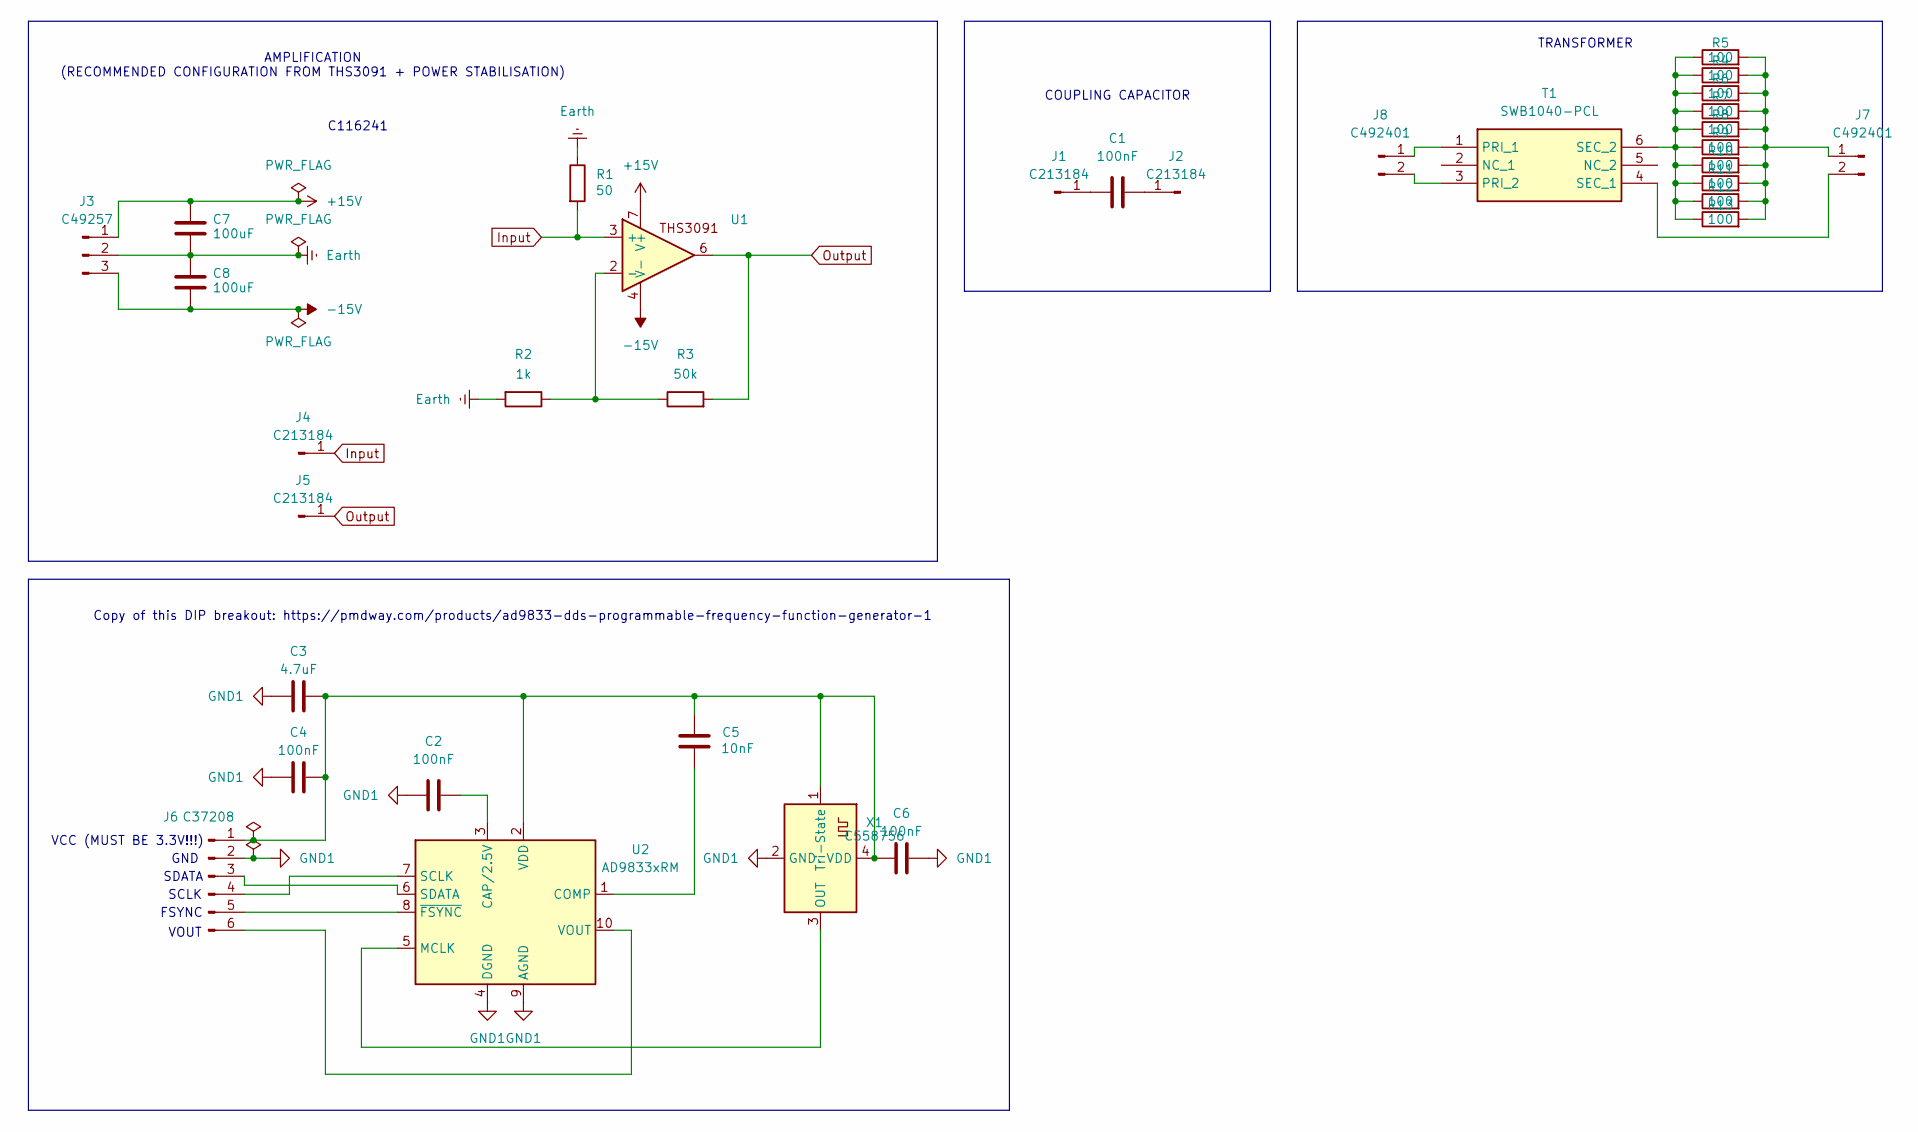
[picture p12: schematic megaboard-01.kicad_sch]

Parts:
C1, C2, C4, C6: C14663; C_0603_1608Metric
C3: C1779; C_0805_2012Metric
C5: C57112; C_0603_1608Metric
C7, C8: C116241; CP_Elec_8x10
J1, J2, J4, J5: C213184; PinHeader_1x01_P2.54mm_Vertical
J3: C49257; PinHeader_1x03_P2.54mm_Vertical
J6: C37208; PinHeader_1x06_P2.54mm_Vertical
J7, J8: C492401; PinHeader_1x02_P2.54mm_Vertical
R1: C849792; R_0603_1608Metric
R2: C21190; R_0603_1608Metric
R3: C166559; R_0402_1005Metric
R4, R5, R6, R7, R8, R9, R10, R11, R12, R13: C17901; R_1206_3216Metric
T1: SWB1040-PCL; SWB1040PCL; Mouser Part Number 994-SWB1040-PCL
U1: THS3091DDAR; TI_SO-PowerPAD-8_ThermalVias
U2: AD9833xRM; MSOP-10_3x3mm_P0.5mm
X1: C558756; Crystal_SMD_7050-4Pin_7.0x5.0mm

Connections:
+15V: C7.1, J3.1, U1.7 (V+)
-15V: C8.2, J3.3, U1.4 (V-)
Earth: C7.2, C8.1, J3.2, R1.1, R2.2
GND1: C2.1, C3.1, C4.1, C6.2, J6.2, U2.4 (DGND), U2.9 (AGND), X1.2 (GND)
Input: J4.1, R1.2, U1.3 (+)
unnamed: C1.1, J1.1
unnamed: C1.2, J2.1
unnamed: C3.2, C4.2, C5.1, C6.1, J6.1, U2.2 (VDD), X1.1 (Tri-State), X1.4 (VDD)
unnamed: J6.3, U2.6 (SDATA)
unnamed: J6.4, U2.7 (SCLK)
unnamed: J6.5, U2.8 (~FSYNC)
unnamed: J6.6, U2.10 (VOUT)
unnamed: J7.1, R4.2, R5.2, R6.2, R7.2, R8.2, R9.2, R10.2, R11.2, R12.2, R13.2
unnamed: J7.2, T1.4 (SEC_1)
unnamed: J8.1, T1.1 (PRI_1)
unnamed: J8.2, T1.3 (PRI_2)
unnamed: R4.1, R5.1, R6.1, R7.1, R8.1, R9.1, R10.1, R11.1, R12.1, R13.1, T1.6 (SEC_2)
unnamed: R2.1, R3.1, U1.2 (-)
unnamed: C2.2, U2.3 (CAP/2.5V)
unnamed: C5.2, U2.1 (COMP)
unnamed: U2.5 (MCLK), X1.3 (OUT)
Output: J5.1, R3.2, U1.6

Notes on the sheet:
Copy of this DIP breakout: https://pmdway.com/products/ad9833-dds-programmable-frequency-function-generator-1
SDATA
VCC (MUST BE 3.3V!!!)
C116241
FSYNC
SCLK
VOUT
AMPLIFICATION (RECOMMENDED CONFIGURATION FROM THS3091 + POWER STABILISATION)
COUPLING CAPACITOR
GND
TRANSFORMER

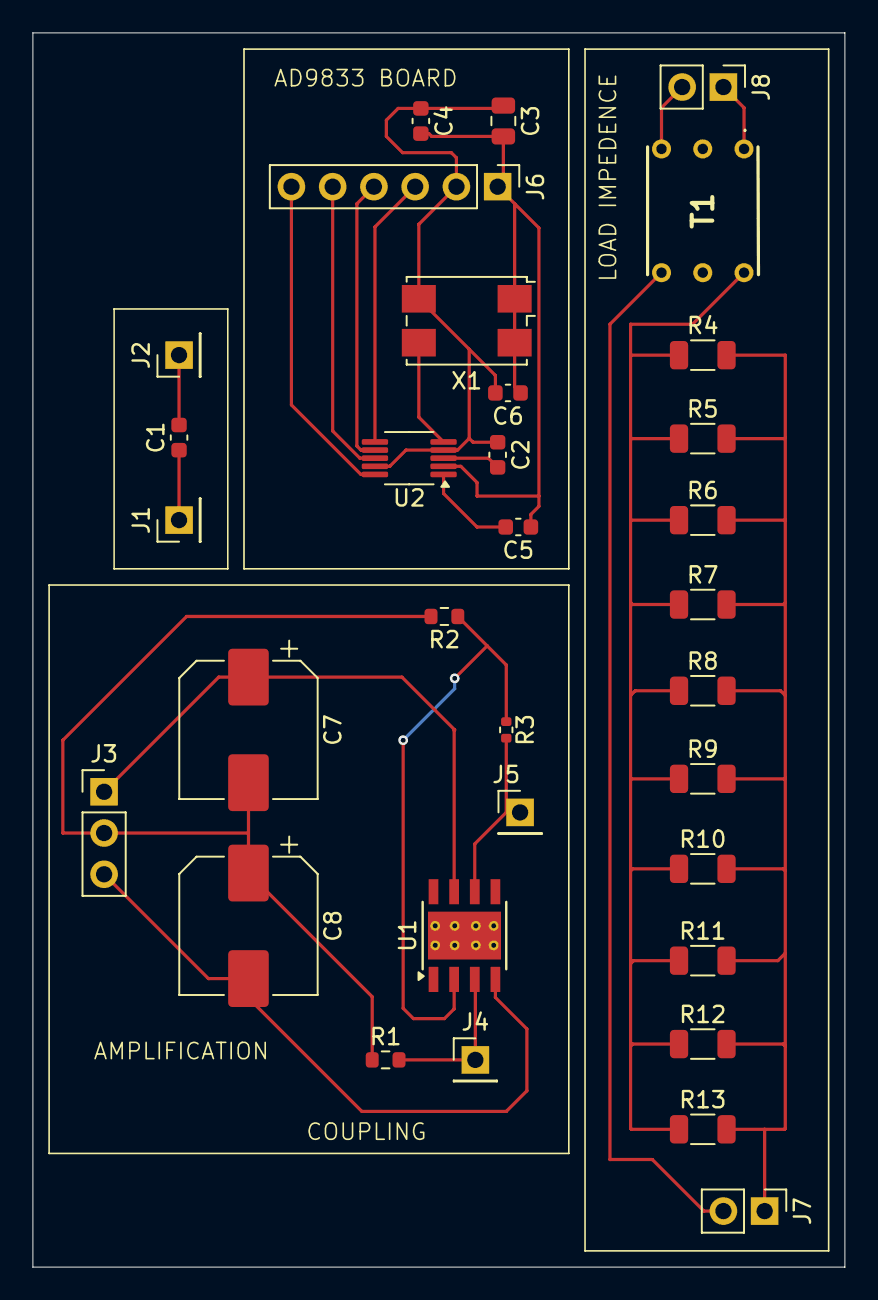
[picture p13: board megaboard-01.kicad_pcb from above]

Board: 2 copper layers, 50.0 x 76.0 mm, 33 parts (0 on the bottom side), 22 nets.

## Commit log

2024-07-03 blender file
    [openFUS-render.blend]
2024-07-04 switch from PMP to PP
2024-07-04 lens cad
    [cad.FCStd]
2024-07-04 add padding
    [cad.FCStd]
2024-07-04 rename to lens!
    [lens.FCStd]
2024-07-04 we switch to cad software
2024-07-05 Rough BOM + reorganization
2024-07-08 got opamp circuit wokring at least, let's lock that in
2024-07-09 driver circuit with actual amplification ???
2024-07-10 more managable level of resistance
2024-07-10 save pzt materials list from steminc
2024-07-10 more power!
2024-07-15 load 3d lens kind of
2024-07-15 put lens in scene
2024-07-15 measure from end of lens
2024-07-16 soldering is hard
2024-07-21 various stuff
    [lens-60mm.step]
2024-07-25 revert more power
2024-08-02 implementation of recommended circuit from data sheet of THS3091
    [BOM-amplification-board.csv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]
2024-08-09 lots of case stuff
    [case.FCStd]
2024-08-11 change megaboard
    [megaboard-01.kicad_pcb, megaboard-01.kicad_sch]
2024-08-11 commit all the kicad stuff for orderliness
    [BOM-new-signal-gen.csv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]
2024-08-11 move all pcb into pcb folder
    [BOM-amplification-board.csv, BOM-new-signal-gen.csv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]
2024-08-11 more order
    [lens-60mm-WAS-MACHINED-IN-PP-BY-XOMETRY.step]
2024-08-11 cad-outputs -> cad/outputs
    [lens-60mm-WAS-MACHINED-IN-PP-BY-XOMETRY.step]
2024-08-11 commit CAD models
    [case.FCStd, lens-concave-PP.FCStd, lens-convex-silicone.FCStd]
2024-08-28 updates to case
    [case.FCStd]
2024-08-29 some stupid shit
    [device.blend, lens-convex-silicone.FCStd, qr-21.stl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]
2024-08-29 fresnel lens!
    [fresnel.scad]
2024-08-29 fix fresnel mold
    [fresnel.scad]
